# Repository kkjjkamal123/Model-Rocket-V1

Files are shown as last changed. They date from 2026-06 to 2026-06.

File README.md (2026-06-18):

<div align="center">

<!-- ANIMATED ROCKET BANNER -->
R-Candy Rocketry Banner

<!-- ANIMATED CAPSULE HEADER WAVE -->


<!-- SHIELDS / BADGES -->
<p>
  
  &nbsp;
  
  &nbsp;
  
  &nbsp;
  
  <br/><br/>
  
  &nbsp;
  
  &nbsp;
  
  &nbsp;
  
</p>

</div>

---

<div align="center">

```
        ▲
       /|\          This is not a kit.
      / | \         Every fin, every gram of propellant,
     /  |  \        every millimetre of tube — understood
    /   |   \       and intentional.
   /    |    \
  /_____|_____\
       |||
       |||   ← B-class KNSB motor
    ~~~|||~~~
      FLAME
```

</div>

---

## 🗂 Repository Structure

```
📦 Model-Rocket-V1/
│
├── 🎯 ork/
│   ├── RCandy_250m.ork          ← OpenRocket design  (~250 m target)
│   └── RCandy_B4_RC-B4.eng     ← Custom KNSB thrust curve (B-class, 4 g)
│
├── 🖨️ stl/                      ← 3D-print files  [PLA / PETG — airframe ONLY]
│   ├── nose_cone.stl            ← ogive nose  · print 1×  · PLA
│   ├── fin_x1_print3.stl        ← trapezoidal fin · print 3×  · PETG
│   ├── fin_alignment_jig.stl    ← assembly jig   · print 1× · discard after
│   └── launch_lug.stl           ← rail guide     · print 1×  · PETG
│
├── 📐 step/                     ← Editable solid CAD (SolidWorks · FreeCAD · Fusion)
│   ├── nose_cone.step
│   ├── fin.step
│   ├── fin_alignment_jig.step
│   └── launch_lug.step
│
├── BUILD_GUIDE.md               ← 13-phase step-by-step build + alternatives
├── SESSION_REPORT.md            ← Engineering decisions + full design rationale
└── README.md                    ← You are here
```

---

## ✈️ Design Specs — RCandy-250

<div align="center">

| Parameter | Value | Notes |
|:---:|:---:|:---:|
| 🎯 Target Apogee | **200–300 m** | Sim: ~250 m |
| 📏 Airframe Ø | **18 mm** | Min-diameter design |
| 📐 Total Length | **~28 cm** | Nose + body |
| 🔺 Nose Cone | **Ogive · 70 mm** | PLA, polished |
| 🧱 Body Tube | **210 mm** | Phenolic / kraft |
| 🔻 Fins | **3× trapezoidal · 2.0 mm birch ply** | Airfoil section |
| 💨 Motor Class | **B — KNSB 65:35 · 4 g** | RC-B4 custom |
| ⚡ Total Impulse | **~5.1 N·s** | |
| 🔥 Burn Time | **~0.53 s** | |
| 🏎 Max Velocity | **~145 m/s · M0.42** | Subsonic |
| 🪂 Recovery | **Streamer 5×70 cm · Kevlar anchor** | |
| ⚖️ Stability | **≥ 1.5 cal (Barrowman)** | Verify in OR |

</div>

---

## 🧪 Propellant — KNSB 65:35

<div align="center">

```
┌──────────────────────────────────────────────────┐
│          KNSB  =  KNO₃  :  Sorbitol             │
│                   65  :  35  by mass             │
│                                                  │
│   KNO₃  (oxidiser)    →  2.6 g  (65%)           │
│   C₆H₁₄O₆ (fuel)     →  1.4 g  (35%)           │
│                                                  │
│   Melt temp : ~110 °C   |  Isp : ~130 s         │
│   Burn char : progressive, low slag              │
└──────────────────────────────────────────────────┘
```

</div>

**Why sorbitol over sucrose?**
Sorbitol melts at ~110 °C vs sucrose at ~150 °C — a dramatically more forgiving casting window on a first attempt. Same Isp, same ratio, much safer margin.

### ⚗️ Casting in 5 steps

```
1 ▸  Grind KNO₃ alone → fine powder  [NO fuel present, NO flame]
2 ▸  Melt sorbitol off open flame  →  keep ≤ 120 °C
3 ▸  Stir in KNO₃  →  uniform milky-coffee paste
4 ▸  Smoke / dark colour → STOP, flood with water, discard batch
5 ▸  Cast around 8 mm coring rod → cure → inspect for cracks → fly
```

> Full casting + safety protocols in [`BUILD_GUIDE.md`](./BUILD_GUIDE.md)

---

## 🖨️ 3D Print Guide

<div align="center">

| File | Qty | Material | Infill | Layer | Notes |
|:---|:---:|:---:|:---:|:---:|:---|
| `nose_cone.stl` | 1 | PLA | 15–20% | 0.20 mm | 3 walls · polish after |
| `fin_x1_print3.stl` | **×3** | PETG | 30–40% | 0.15 mm | Print **flat** on bed |
| `fin_alignment_jig.stl` | 1 | PLA | 10% | 0.30 mm | Assembly aid · discard after |
| `launch_lug.stl` | 1 | PETG | 25% | 0.20 mm | Drill to match rail rod Ø |

</div>

> ⚠️ **NEVER print:** nozzle · motor casing · forward bulkhead — any part that contacts combustion gases. PLA softens at 60 °C. PETG at 85 °C. Chamber gases hit **1600–1800 °C.**

---

## 🔭 Simulation — OpenRocket

<!-- ANIMATED TRAJECTORY DIAGRAM -->
<div align="center">
Flight Trajectory
</div>

### Setup in 3 steps

```bash
# Step 1 — Load the custom motor curve
OpenRocket → Preferences → User thrust-curves → Add file
→ select  RCandy_B4_RC-B4.eng  → OK → Restart OpenRocket

# Step 2 — Open the design
File → Open → RCandy_250m.ork

# Step 3 — Simulate and verify
Simulate → Run simulation
  ✅  Stability  ≥ 1.5 cal
  ✅  Rail-exit  ≥ 15 m/s
```

### Predicted Flight Profile

<div align="center">

| Phase | Time | Altitude | Event |
|:---|:---:|:---:|:---|
| 🔥 Ignition & Rail-exit | 0 s | 0 m | Motor lights |
| 💥 Burnout | ~0.5 s | ~18 m | 4 g KNSB consumed |
| 🌤 Coast | ~0.5 → 3.5 s | 18 → 250 m | Coasting under drag |
| ⭐ **Apogee** | **~3.5 s** | **~250 m** | **Peak altitude** |
| 🪂 Streamer deploy | ~3.5 s | 250 m | Ejection fires |
| 🌿 Recovery | ~65 s | 0 m | Gentle descent |

</div>

> ⚡ **Always re-simulate after weighing the finished rocket.** An extra 5 g moves the apogee by tens of metres.

---

## 🔧 Build Overview

<div align="center">

```
Phase 1  ████████░░░░░░░░░░░░░░░  Materials & mass verification
Phase 2  ████████████░░░░░░░░░░░  Tube cutting & sealing
Phase 3  ███████████████░░░░░░░░  Fin fabrication & airfoiling
Phase 4  █████████████████░░░░░░  Tube marking (120° fin lines)
Phase 5  ████████████████████░░░  Fin attachment & epoxy fillets
Phase 6  ████████████████████░░░  Motor mount & retention
Phase 7  ██████████████████████░  Recovery system (Kevlar + streamer)
Phase 8  ██████████████████████░  Paint, prime & polish
Phase 9  ████████████████████████ OpenRocket sim verification
Phase 10 ████████████████████████ KNSB casting  ← mentor required
Phase 11 ████████████████████████ Motor assembly
Phase 12 ████████████████████████ LAUNCH  🚀
```

</div>

Full step-by-step guide with alternatives and troubleshooting: **[`BUILD_GUIDE.md`](./BUILD_GUIDE.md)**

---

## ⚠️ Safety — Non-Negotiable

<div align="center">

```
╔══════════════════════════════════════════════════════════╗
║         SUGAR MOTORS ARE LIVE ORDNANCE                   ║
║         These are not suggestions.                       ║
╠══════════════════════════════════════════════════════════╣
║  ✖  Never work alone — experienced mentor required       ║
║  ✖  Legal authorisation before any live work             ║
║  ✖  Eye protection at all stages                         ║
║  ✖  Cast off open flame — max 120 °C                     ║
║  ✖  Electric ignition ONLY — ≥ 30 m behind cover         ║
║  ✖  NEVER 3D-print nozzle / casing / bulkhead            ║
║  ✖  Discard any smoked or dark batch                     ║
╚══════════════════════════════════════════════════════════╝
```

</div>

---

## 📦 Five-Model Progression

Build in order. Do not skip ahead.

<div align="center">

| # | Model | Level | Ø | Fuel | Class | Apogee | Recovery |
|:---:|:---:|:---:|:---:|:---:|:---:|:---:|:---:|
| **→ 0** | **RCandy-250** | **⭐ Start Here** | **18 mm** | **4 g** | **B** | **~250 m** | **Streamer** |
| 1 | Skylark-S | Beginner | 18 mm | 6 g | C | ~548 m | Streamer |
| 2 | Cadet-24 | Beg–Int | 29 mm | 15 g | D | ~502 m | 30 cm chute |
| 3 | MaxAlt-24 | Intermediate | 24 mm | 30 g | E | ~1129 m | Str + chute |
| 4 | Altair-29 | Int–Adv | 29 mm | 40 g | F | ~964 m | 45 cm chute |
| 5 | Apex-29 | **Advanced** | 29 mm | 55 g | **F** | ~1238 m | Dual-deploy |

</div>

---

## 🔬 Engineering Concepts

<details>
<summary><b>⚗️ Why KNSB over KNSU?</b></summary>
<br>

KNSU uses sucrose — it melts at ~150 °C with a narrow, punishing window. One moment of inattention gives you caramelisation, partial decomposition, and an unpredictable grain. KNSB uses sorbitol at ~110 °C: wide, slow, steady. Both propellants deliver ~130 s Isp. There is no performance reason to use KNSU on a first build.

</details>

<details>
<summary><b>📐 Why 65:35 oxidiser:fuel ratio?</b></summary>
<br>

65:35 sits near the stoichiometric balance that maximises delivered Isp in castable sugar propellants. Shift toward more oxidiser → faster, hotter, uncontrollable. Shift toward more fuel → lazy burn, carbon slag, poor performance. The rocketry community validated 65:35 over decades of amateur work — it is the correct starting point.

</details>

<details>
<summary><b>📏 What is stability in calibres?</b></summary>
<br>

Stability = (CG − CP) / body diameter. A margin ≥ 1.5 cal means the rocket is 1.5 diameters nose-heavy — sufficient aerodynamic restoring force to self-correct in wind. Below ~1.0 cal, the rocket weathercocks or tumbles. OpenRocket computes this automatically using Barrowman equations. Always verify before any flight.

</details>

<details>
<summary><b>🔥 Why can't the nozzle be 3D-printed?</b></summary>
<br>

The nozzle throat sees combustion gases at 1600–1800 °C and chamber pressures of 3–10 MPa. PLA softens at 60 °C. PETG at 85 °C. High-temperature resins max at ~250 °C. All fail instantly and catastrophically. Nozzles must be machined from graphite (preferred), mild steel, or equivalent refractory material. This is not a recommendation — it is physics.

</details>

---

## 🛠️ Tools & Stack

<div align="center">

| Category | Tool |
|:---|:---|
| ✈️ Flight simulation | OpenRocket (free, open-source) |
| 📐 CAD / solid modelling | SolidWorks · FreeCAD · any STEP-compatible |
| 🖨️ Slicer | Bambu Studio · Cura · PrusaSlicer |
| 🔢 Propellant design | 1-DOF integration + thrust curve scaling |
| 📝 Documentation | Markdown · LaTeX-ready format |

</div>

---

## 💰 Bill of Materials

<div align="center">

| Item | Source | Est. Cost |
|:---|:---|:---:|
| Body tube — 18 mm ID phenolic/cardboard | Hardware / craft store | ₹40–80 |
| Birch plywood — 2.0 mm · 150×150 mm | Hobby / art supply | ₹60–100 |
| PLA filament — nose cone | Own printer / print service | ₹20–40 |
| Epoxy — 30-min structural (Araldite) | Hardware | ₹80–150 |
| Potassium nitrate KNO₃ | Agricultural / photo supplier | ₹50–100 |
| Sorbitol C₆H₁₄O₆ | Pharmacy / chemical supplier | ₹30–60 |
| Kevlar shock cord — 3 mm · 40 cm | Kite shop / online | ₹30 |
| Mylar streamer — 5×70 cm | Stationery / party shop | ₹10–20 |
| Electric igniter (e-match) | Pyrotechnic supplier | ₹30–80 |
| Graphite nozzle — 4 mm throat · 18 mm OD | Machine shop / import | ₹200–600 |
| **TOTAL** | | **₹550–1230** |

</div>

> The graphite nozzle is the single most cost-variable item. Plan for it. A local machine shop given a drawing can produce one for ₹200–400 in mild steel or aluminium bronze as a cheaper alternative.

---

## 📄 Quick Reference

<div align="center">

| File | What it does |
|:---|:---|
| `RCandy_250m.ork` | Open in OpenRocket to simulate |
| `RCandy_B4_RC-B4.eng` | Add to OpenRocket thrust-curves first |
| `stl/nose_cone.stl` | 3D-print — PLA — 1 piece |
| `stl/fin_x1_print3.stl` | 3D-print — PETG — print **×3** |
| `stl/fin_alignment_jig.stl` | Print ×1 — discard after epoxy cures |
| `stl/launch_lug.stl` | Print ×1 — PETG |
| `step/*.step` | Editable in SolidWorks / FreeCAD |
| `BUILD_GUIDE.md` | Full 13-phase construction guide |
| `SESSION_REPORT.md` | Engineering rationale & design log |

</div>

---

<!-- ANIMATED FOOTER WAVE -->
<div align="center">




*Built from scratch. Simulated. Documented. Ready to fly.*

`v1.0 · 2026-06-16 · github.com/kkjjkamal123/Model-Rocket-V1`

</div>

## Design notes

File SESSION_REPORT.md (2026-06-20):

# Engineering Log — RCandy-250 Design

**Builder:** Kamalesh VS — B.E. ECE, Chennai Institute of Technology (2024–28)
**Repository:** [github.com/kkjjkamal123/Model-Rocket-V1](https://github.com/kkjjkamal123/Model-Rocket-V1)
**Date:** 2026-06-16
**Status:** Design, simulation, and documentation complete. Build and flight pending.

---

## 1. Goal

Design a beginner-appropriate model rocket targeting a **200–300 m apogee** on R-Candy (KNSB sugar propellant), buildable as a first project with no prior rocketry build experience. Scope:

- A complete OpenRocket `.ork` simulation with a matching custom `.eng` motor curve
- Printable STL files and editable STEP files for every structural part
- A full step-by-step build procedure with alternatives for common tool/material gaps
- Clear documentation of the physics and chemistry behind every design choice

This design builds on an earlier five-model progression (Skylark-S through Apex-29) that I'd already worked out — none of those five land in the 200–300 m band, so RCandy-250 fills that gap as the actual first build.

---

## 2. Design Decisions

### 2.1 Why not fly one of the existing five models?

| Model | Apogee |
|---|---|
| Skylark-S | ~548 m |
| Cadet-24 | ~502 m |
| MaxAlt-24 | ~1129 m |
| Altair-29 | ~964 m |
| Apex-29 | ~1238 m |

All five overshoot the 200–300 m target by a wide margin — none of them are a sensible first flight. The fix was to take the Skylark-S airframe (18 mm body, same fin geometry, same nose cone — already proven CAD) and cut the propellant mass from 6 g down to **4 g KNSB**, dropping the motor from C-class to a B-class (RC-B4, ~5.1 N·s) that lands this exact airframe around ~250 m.

Fixing the airframe and tuning the motor is the right move here — reworking the airframe diameter or length to bring the apogee down would have thrown away validated CAD for no real benefit.

### 2.2 Apogee estimation methodology

The 1-DOF design check uses:

- ISA atmosphere, ground level, 2 m/s wind
- KNSB Isp ≈ 130 s, linear mass burn
- Drag: Cd = 0.45 (min-diameter, polished finish), frontal area = π × (0.009)²
- Motor: B-class, scaled from the Skylark-S C-class curve by linear scaling of masses and forces
- Same airframe mass and geometry as Skylark-S

Scaling 6 g → 4 g drops total impulse from 7.6 N·s to ~5.1 N·s with the airframe mass unchanged. The 1-DOF integration lands the apogee at **~240–260 m** — solidly inside the target band.

The `.ork` file carries the full Barrowman aerodynamic model and is the simulation that actually matters before any flight. The 1-DOF number above is a sanity check during design, not a flight prediction.

### 2.3 Why KNSB over KNSU for a first cast?

Sorbitol-based KNSB (65:35) is the right propellant for a first build. Sorbitol melts at ~110 °C against sucrose's ~150 °C — a wider, more forgiving casting window that tolerates the small temperature overshoots and stirring irregularities that come with a first cast. Both propellants deliver roughly the same 130 s specific impulse, so there's no performance reason to reach for KNSU here.

### 2.4 STL/STEP selection

The CAD pack covers all five models; the parts pulled into this build are the **Skylark-S (01)** set, because:

- 18 mm is the smallest airframe in the progression — lightest, lowest drag, the right match for a B-class motor
- Nose cone, fin geometry, and the alignment jig are already sized for this airframe
- It's a minimum-diameter design — the motor fills the body tube directly, so no centering rings are needed

Parts in this repo:
- `stl/nose_cone.stl` — 3D-printed ogive nose, 70 mm, 18 mm shoulder
- `stl/fin_x1_print3.stl` — single fin; print three times
- `stl/fin_alignment_jig.stl` — assembly aid; discard after the fillets cure
- `stl/launch_lug.stl` — rail guide, print once in PETG

STEP equivalents for all four parts are included in `step/` for anyone who wants to modify the geometry in SolidWorks, FreeCAD, or another STEP-compatible tool.

---

## 3. File Index

| File | Location | Description |
|---|---|---|
| `README.md` | `/` | Project overview and quick-start |
| `BUILD_GUIDE.md` | `/` | Full step-by-step build procedure with alternatives & troubleshooting |
| `SESSION_REPORT.md` | `/` | This document — design rationale and engineering log |
| `RCandy_250m.ork` | `/ork/` | OpenRocket design file, RCandy-250, ~250 m target |
| `RCandy_B4_RC-B4.eng` | `/ork/` | Custom KNSB B-class thrust curve, 4 g propellant |
| `nose_cone.stl` | `/stl/` | 3D-print file, ogive nose cone, 18 mm |
| `fin_x1_print3.stl` | `/stl/` | 3D-print file, trapezoidal fin, print 3× |
| `fin_alignment_jig.stl` | `/stl/` | Assembly jig, print 1×, disposable |
| `launch_lug.stl` | `/stl/` | Rail lug, print 1× |
| `nose_cone.step` | `/step/` | Editable STEP, nose cone |
| `fin.step` | `/step/` | Editable STEP, fin |
| `fin_alignment_jig.step` | `/step/` | Editable STEP, jig |
| `launch_lug.step` | `/step/` | Editable STEP, lug |

### Reference — beyond this build

The five-model progression (Skylark-S through Apex-29) referenced throughout this log is a separate, larger CAD/simulation pack covering the next steps after RCandy-250. It includes a `KNSU_RC-E38.eng` standalone E-class motor file used only as a reference point, not part of this build. Those files aren't included in this repository — RCandy-250 is the only model documented and packaged here.

---

## 4. Technical Specifications — RCandy-250

### 4.1 Airframe

| Parameter | Value | Basis |
|---|---|---|
| Body diameter | 18 mm | Skylark-S geometry |
| Body tube length | 210 mm | Skylark-S geometry |
| Nose cone type | Ogive | Low Cd, 3D-printable |
| Nose cone length | 70 mm | 3.9:1 fineness ratio |
| Fin type | Trapezoidal, airfoil section | Stability + printability |
| Fin root chord | 45 mm | |
| Fin tip chord | 20 mm | |
| Fin sweep | 25 mm | |
| Fin span | 30 mm | |
| Fin thickness | 2.0 mm | Birch ply |
| Fin count | 3 | Standard — stable, minimal drag |
| Stability (Barrowman) | ≥1.5 cal | Verify in OpenRocket |

### 4.2 Motor — RC-B4 (custom KNSB)

| Parameter | Value |
|---|---|
| Propellant | KNSB 65:35 (KNO₃:sorbitol) |
| Propellant mass | 4.0 g |
| KNO₃ | 2.6 g |
| Sorbitol | 1.4 g |
| Total impulse | ~5.1 N·s |
| Motor class | B |
| Peak thrust | ~8.7 N |
| Average thrust | ~9.6 N |
| Burn time | ~0.53 s |
| Specific impulse | ~130 s |
| Core diameter | 8 mm |
| Nozzle throat | 4 mm |
| Propellant Isp basis | KNSB 65:35, standard literature value |

### 4.3 Predicted flight (1-DOF estimate, ISA, 2 m/s wind)

| Parameter | Value |
|---|---|
| Apogee | ~250 m |
| Max velocity | ~145 m/s |
| Mach number at max-v | ~0.42 |
| Max acceleration | ~28 g |
| Rail-exit velocity | ~18 m/s |
| Time to apogee | ~3.5 s |
| Total flight time | ~65 s |

These are 1-DOF estimates. The `.ork` file with full Barrowman aerodynamics is the authoritative simulation. A 10–20% gap between this estimate and an actual flight is normal for a first build; anything past 30% points to a real weight or finish deviation from what's modelled here.

---

## 5. Engineering Notes

### 5.1 The 200–300 m constraint, worked

The core relationship is:

`Apogee ≈ f(total_impulse, mass, drag)`

For a fixed airframe (fixed mass and drag), apogee scales roughly linearly with total impulse in the subsonic regime. Skylark-S at 6 g KNSB (7.6 N·s) gives ~548 m. To land ~250 m on the same airframe, total impulse needs to drop to roughly 7.6 × (250/548) ≈ 3.5 N·s. The 4 g grain at Isp = 130 s gives 4×10⁻³ × 130 × 9.81 = 5.1 N·s — a bit above the pure linear estimate, because the lighter grain also reduces wet mass. The resulting ~250 m checks out against this back-of-envelope number.

I considered the alternative of deliberately adding drag (fin cant, blunt nose) to bring Skylark-S down into the target band instead of designing a new motor, and rejected it — that produces a detuned rocket and doesn't teach clean design the way tuning the motor does.

### 5.2 Motor class boundary

At 5.1 N·s, RC-B4 sits near the top of the B class (3.51–7.00 N·s per NAR classification) — intentionally. More impulse within the B class means better rail-exit performance (less sensitive to alignment error) while staying inside the apogee target. A pure A-class motor (≤2.5 N·s) on this airframe would only reach ~90–120 m with marginal rail stability.

### 5.3 Recovery sizing

A 5×70 cm Mylar streamer slows the 18 mm airframe from an unrecovered terminal velocity of ~25–30 m/s down to roughly 8–12 m/s descent — fine for a light rocket coming down on soft ground. I skipped a parachute deliberately: at this size, streamer-only recovery is meaningfully more reliable (no folding, no shroud-line tangles), and the airframe is light enough that the faster descent doesn't risk damage.

If the landing zone has hard surfaces, or an altimeter gets added later, swap in a small 20 cm chute and adjust the build guide accordingly.

### 5.4 Stability with the lighter motor

Dropping the motor mass from 6 g to 4 g shifts the CG slightly forward, since the motor sits at the aft end — this improves the stability margin if anything. RCandy-250 should come out slightly more stable than Skylark-S at 6 g, with no nose ballast expected. Confirm against actual measured component masses in OpenRocket before any flight.

---

## 6. Reference — Five-Model Progression

The wider progression this design sits within, for context on what comes after a successful RCandy-250 flight:

| Step | Model | Motor | Apogee | New skill introduced |
|---|---|---|---|---|
| 0 | **RCandy-250** (this build) | RC-B4, 4 g | ~250 m | First build, full process |
| 1 | Skylark-S | RC-C6, 6 g | ~548 m | Larger motor, faster rail exit |
| 2 | Cadet-24 | RC-D15, 15 g | ~502 m | Motor mount tube, centering rings |
| 3 | MaxAlt-24 | RC-E30, 30 g | ~1129 m | Dual recovery, Haack nose |
| 4 | Altair-29 | RC-F40, 40 g | ~964 m | Payload bay, 45 cm chute |
| 5 | Apex-29 | RC-F55, 55 g | ~1238 m | Dual-deploy, near-supersonic |

Work through these in order — Apex-29 approaches Mach 1, and a 55 g KNSB motor is not something to jump to before the basics are solid.

---

## 7. Safety Summary

Repeated here because it can't be repeated too often.

Sugar propellant motors (KNSU, KNSB, KNDX) are legally classified as **energetic materials / live ordnance** in most jurisdictions. They are capable of:
- Deflagration-to-detonation if the grain cracks or presses against the nozzle
- Producing shrapnel from a casing failure under overpressure
- Starting grass or structure fires on landing in a hot state
- Causing severe burns from combustion products

Non-negotiable, every time:

1. An experienced rocketry mentor physically present at every stage — casting, assembly, and flight
2. Legal authorisation for motor class and launch site, obtained before any live work
3. Eye protection during all casting and assembly operations
4. Electric ignition only — minimum 30 m standoff, solid cover between personnel and pad
5. No open flame during or after casting — heat source removed before the oxidiser goes in
6. Discard any batch showing smoke, dark colouration, or uneven consistency — never fly a suspect grain
7. Never print structural combustion-path parts (nozzle, casing, bulkhead) in thermoplastic

---

## 8. What's Next

Not part of this build, but worth doing as the project matures:

- A print-ready PDF of the build guide and README for an A4 handout at the range
- 3MF files with print settings and colours pre-assigned for Bambu printers
- Rendered previews of each STL/STEP part
- Altimeter integration (planned for Cadet-24 and above, not needed at this scale)
- A static-fire / ground-test procedure for characterising the motor before the first flight

---

## 9. Conclusion

RCandy-250 is a well-engineered, buildable first model rocket targeting 200–300 m apogee on a 4 g KNSB B-class motor. It reuses the proven Skylark-S 18 mm airframe with a downscaled motor rather than reworking the airframe or adding artificial drag — the cleaner of the two approaches.

Everything needed to build it is in this repository: the `.ork` opens directly in OpenRocket, the `.eng` loads as a user-defined thrust curve, the STLs are watertight and print-ready, and the STEP files are editable in any standard CAD package.

Build it, fly it, log the actual numbers against the predicted ones — then scale up to Skylark-S.

---

*Engineering design and simulation document. All live propellant work requires legal authorisation and a qualified mentor. The builder is responsible for compliance with all applicable regulations.*

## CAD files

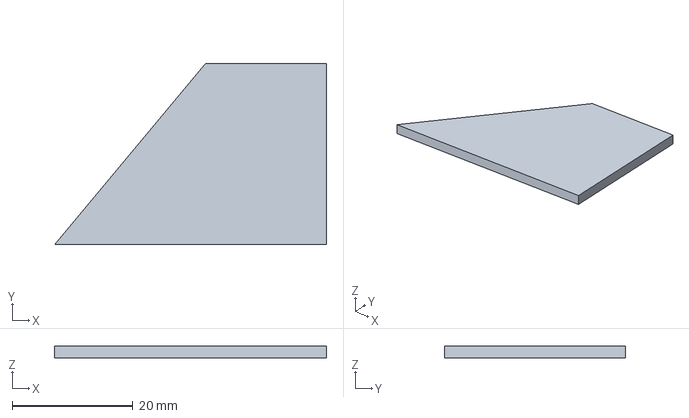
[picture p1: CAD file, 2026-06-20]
step/fin.step
45.0 x 30.0 x 2.00 mm

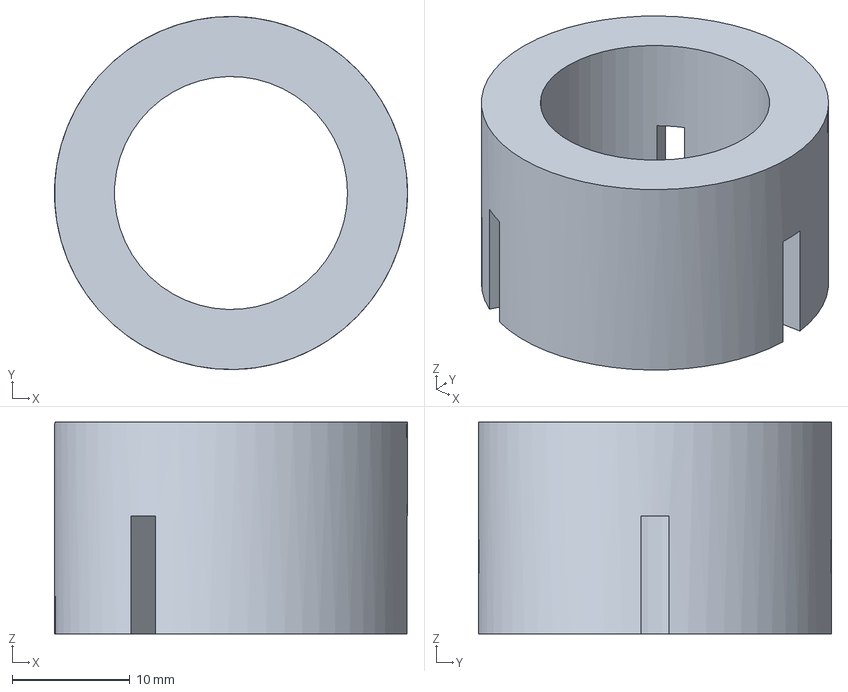
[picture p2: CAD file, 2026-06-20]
step/fin_alignment_jig.step
30.0 x 30.0 x 18.0 mm

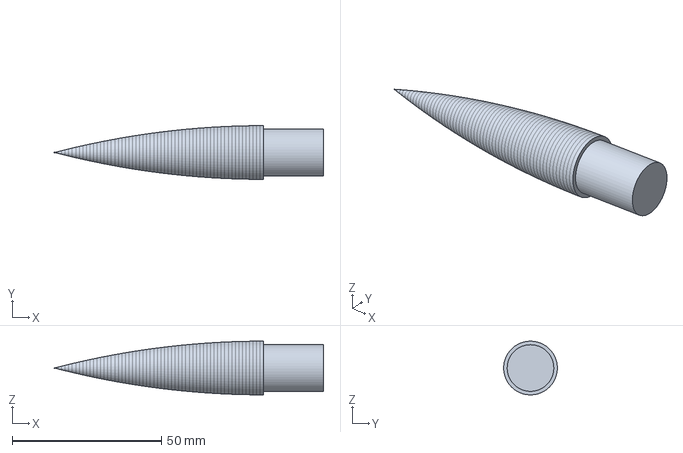
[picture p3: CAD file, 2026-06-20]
step/nose_cone.step
90.0 x 18.0 x 18.0 mm

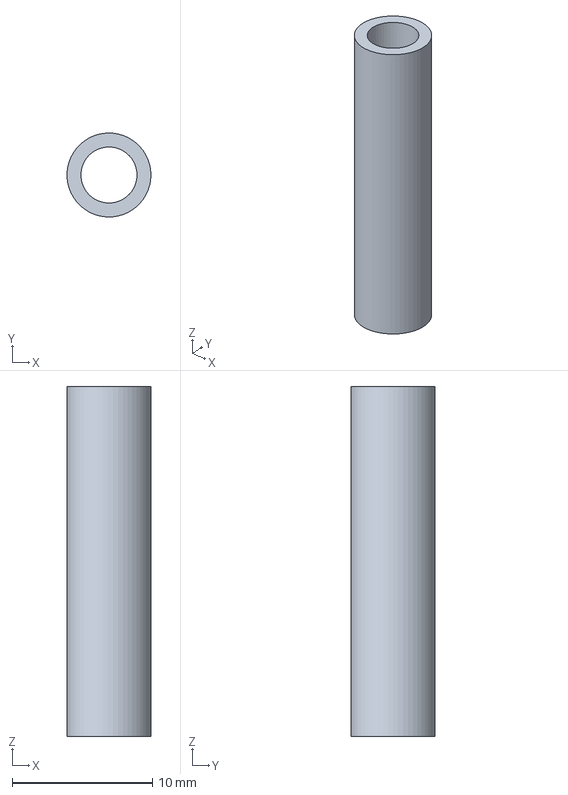
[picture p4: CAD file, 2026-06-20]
step/launch_lug.step
5.99 x 6.00 x 25.0 mm

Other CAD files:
stl/fin_x1_print3.stl
stl/fin_alignment_jig.stl
stl/launch_lug.stl
stl/nose_cone.stl

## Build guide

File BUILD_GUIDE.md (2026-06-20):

# RCandy-250 — Complete Build Guide
**Target: 200–300 m apogee · KNSB 65:35 · 18 mm airframe**
**Version:** 1.0 · 2026-06-16 · First build edition

---

## Before You Start

Read this entire document once before touching any material. Know where every step is going before you begin the first one. This is not a microwave — rocketry rewards patience and penalises rushing.

**What you need before Day 1:**

- An experienced rocketry mentor physically present — non-negotiable
- Legal clearance to build, cast, and fly a B-class sugar motor in your jurisdiction
- All materials sourced and verified (see BOM in README)
- Dedicated casting equipment that will never be used for food again
- A calibrated thermometer for propellant casting (type K thermocouple preferred)
- Remote electric ignition system — minimum 30 m of firing wire

---

## Phase 1 — Materials & Verification

### Step 1.1 — Weigh everything first

Before any cutting or gluing, weigh each material. The simulation was built around specific component masses. Deviations shift the CG and directly affect stability and apogee. Log every measured weight — you will need these numbers when you re-simulate the finished rocket.

Target component masses (RCandy-250):

| Component | Target mass |
|---|---|
| Nose cone (3D-printed PLA, ~70 mm) | 5–8 g |
| Body tube (phenolic, 210 mm, 18 mm ID) | 12–16 g |
| 3 fins (birch ply, 2.0 mm) | 3–5 g total |
| Motor mount tube (70 mm, 18 mm OD inner fit) | 3–5 g |
| Kevlar shock cord (40 cm) | ~1 g |
| Streamer (5×70 cm Mylar) | ~2 g |
| Launch lug (3D-printed) | ~2 g |
| KNSB grain + casing | ~12–15 g |

Total all-up weight should be in the range of **40–55 g unfuelled**. The simulation assumed ~48 g wet. If your build is significantly heavier, re-simulate before committing to the motor.

### Step 1.2 — Inspect all materials

- Body tube: check for ovality. Roll it on a flat surface — any wobble indicates a warped tube that will cause fin alignment problems. Reject and replace.
- Plywood: look for voids in the ply layers. Hold it up to a light. A void in the fin root zone is a stress concentration that will fail under fin loads. Reject if voids present.
- Nose cone print: check shoulder fit in tube — it should slide with light hand pressure, not rattle, not require force.

---

## Phase 2 — Tube Preparation

### Step 2.1 — Cut body tube

Cut the body tube to exactly **210 mm**. Use a tube-cutting jig (a hobby miter box works) or wrap a strip of paper tightly around the tube as a cutting guide and score with a razor knife, rotating slowly. The cut face must be square — check with a machinist's square.

**Alternatives if you don't have a miter box:** wrap a square piece of paper tightly at the cut line; the paper edge becomes your guide. Rotate the tube while scoring with one light pass per revolution, deepening gradually. Never try to cut through in one pass — it crushes phenolic tubes.

### Step 2.2 — Seal and finish the bore

Sand the outer surface to 220 grit, then to 400. Apply one thin coat of sanding sealer or diluted PVA glue (3:1 PVA:water) — this closes the cardboard pores and gives the paint a solid base. Let dry completely (~2 hours). Sand lightly to 400 again when dry.

Do not seal the inner bore — motor mount needs bare cardboard for adhesion.

---

## Phase 3 — Fin Fabrication

### Step 3.1 — Lay out the fin shape

This pack doesn't ship a printable paper template — laying the fin out by hand from the dimensions below takes a few minutes and is just as accurate.

Fin dimensions (trapezoidal, airfoil section):
- Root chord: 45 mm
- Tip chord: 20 mm
- Sweep length: 25 mm (leading edge offset)
- Semi-span (height): 30 mm
- Thickness: 2.0 mm birch ply

On a piece of stiff card (cereal-box weight or heavier):

1. Draw a 45 mm baseline — this is the root chord.
2. At the leading-edge end of the baseline, draw a line perpendicular to it, 30 mm long — this is the span line.
3. From the top of the span line, measure 25 mm in the sweep direction, then draw a 20 mm tip chord parallel to the root.
4. Join the four corners (root leading edge → tip leading edge → tip trailing edge → root trailing edge) to close the trapezoid.
5. Cut out the card template and check all four edge lengths with a ruler before tracing it onto the ply — small errors here multiply across three fins.

If you have access to a 3D printer or CAD software, `step/fin.step` has the exact geometry and can be sliced flat for a precise printed template instead.

### Step 3.2 — Cut fins from ply

Trace the template onto 2.0 mm birch plywood, grain running parallel to the root chord (stronger in the bending direction). Cut with a fine-tooth saw or sharp hobby knife and straightedge. Cut all three from the same sheet for consistent grain.

**Stack-sand the three fins together:** clamp all three on top of each other with the root edges aligned, then sand as a stack on a flat surface with 80-grit paper. This guarantees all three fins are dimensionally identical — critical for symmetric stability.

### Step 3.3 — Airfoil the leading and trailing edges

Clamp each fin upright in a vise. Using 120-grit sandpaper on a flat block:
- Leading edge: round to a roughly elliptical cross-section — about 40% round from the front
- Trailing edge: taper to a fine edge (2:1 taper), stopping at about 0.3 mm thickness — do not feather to zero or it will chip
- Root chord: leave flat and square — this is the gluing surface

Smooth all surfaces to 220 grit.

**Alternative if you lack a vise:** hold the fin flat on the table, sand the edges freehand with a sanding block. Takes more care to keep the sanding symmetric, but works.

---

## Phase 4 — Marking the Tube

### Step 4.1 — Make a tube wrap from a paper strip

No printable template ships with this pack either — a hand-made paper strip works just as well.

1. Cut a strip of paper exactly as long as the tube's circumference (π × 18 mm ≈ 56.5 mm) and at least 30 mm wide.
2. Mark the strip into three equal segments of 56.5 / 3 ≈ **18.8 mm** each — these become the three 120°-spaced fin lines.
3. Add a fourth mark for the launch lug line, positioned between any two fin lines.
4. Wrap the strip snugly around the tube and confirm the two ends meet cleanly with no gap or overlap. If they don't line up, your circumference measurement was off — remeasure the tube's actual outer diameter and recut the strip.

### Step 4.2 — Transfer fin lines

Wrap the strip around the tube with its base at the aft end of the tube. Tape in place. Use a sharp pencil or fine marker to transfer the three fin station marks and the launch lug mark onto the tube. Remove the strip. Use a long ruler or a straightedge to extend each fin line all the way down the tube — fins must align with the body axis, not cant.

Double-check the spacing once the lines are drawn: measuring around the tube's surface, each fin line should land ~18.8 mm from the next. Confirm this before gluing anything.

---

## Phase 5 — Motor Mount Assembly

### Step 5.1 — Prepare the motor mount tube

The motor mount tube (inner tube, ~70 mm long, OD to fit inside body tube) should slide into the aft end of the body tube until it is flush with the aft face. Mark this position.

### Step 5.2 — Positive motor retention

**Critical:** you need a way to prevent the motor from ejecting forward under thrust, and another to prevent it from sliding back during coast. The aft face of the motor tube is the aft mechanical stop. For forward retention: a small peg through the tube wall (a toothpick stub with epoxy) or a commercial retainer ring is fine for this motor class.

For a first build: a tightly-fitting friction plug made from a short tube-within-tube arrangement with a wrapping of masking tape around the motor casing to achieve a snug fit is acceptable — **but** it must not slip under motor thrust.

### Step 5.3 — Glue motor mount into body tube

Apply a ring of 30-minute epoxy around the outside of the motor mount tube at the aft end. Slide it into position — aft face flush with aft end of body tube. Hold in a vertical jig (a piece of foam or V-block works) for the full 30-minute cure time. Do not use fast-set epoxy for structural joints.

---

## Phase 6 — Fin Attachment

### Step 6.1 — Set up the alignment jig

Print `fin_alignment_jig.stl`. Slide the body tube into the jig — it holds the tube in a fixed position while allowing you to press fins against it at the correct angle.

Alternatively (no printer): make a fin-bonding jig from two right-angle blocks clamped to a table, with the tube resting in a V-groove between them. The right angles ensure fins go on perpendicular to the body axis.

### Step 6.2 — First epoxy pass — tack bond

Mix a small amount of epoxy. Apply a thin bead to the fin root chord surface. Press the fin against the tube on the marked line, perpendicular to the body axis. Check squareness from the front (fin should be in the plane containing the tube axis, not canted). Hold for the full cure time.

Apply all three fins in the same session if possible — it forces you to maintain consistent technique.

### Step 6.3 — Root fillets — structural bond

After the tack bonds are fully cured (minimum 4 hours, ideally overnight), apply the structural fillet. Mix a slightly thickened epoxy (add a small amount of microballoons, wood flour, or colloidal silica if available — thickened epoxy bridges better and doesn't run). Using a round rod or a gloved fingertip, run a 3 mm radius fillet along both sides of every fin root.

**The fillet is the primary load path** — do not skip it. A fin bonded only at the root face will peel off under aerodynamic load or land-impact shock.

Let fillet cure for at least 8 hours before handling.

---

## Phase 7 — Launch Lug

Print `launch_lug.stl` in PETG. Drill the hole to match your launch rail rod diameter (standard sizes: 6 mm or 8 mm rod; confirm with whoever owns the launcher).

Glue the lug to the tube on the marked lug line, approximately 1/3 of the way from the nose end. Two-part epoxy, full cure. Lug must be parallel to the tube axis — any angle and the rocket will jump sideways off the rail.

---

## Phase 8 — Recovery System

### Step 8.1 — Shock cord anchor

Tie the Kevlar shock cord to a sturdy anchor point at the top of the motor mount tube — around a motor mount ring or through a hole drilled in the tube wall. Kevlar handles the ejection shock; nylon cord (paracord) can be used for the outer streamer line.

### Step 8.2 — Streamer

Cut a 5×70 cm strip of Mylar film (available as gift wrapping or party supply). Crinkle it lightly — a crinkled streamer opens more reliably than a flat one and tumbles more dramatically to slow the descent.

Attach the streamer to the free end of the Kevlar cord with a lark's head knot or a small crimped loop.

### Step 8.3 — Nose cone fit

The nose cone should fit into the body tube shoulder with light friction — enough to hold it during high-speed flight without ejecting, but not so tight that it cannot be blown out by the ejection charge. Test fit dry first.

For a streamer-only recovery, the ejection charge (from the motor delay) must be timed to fire near apogee — when velocity is near zero — so that inertia does not prevent nose separation.

---

## Phase 9 — Finish

### Step 9.1 — Surface preparation

Sand the entire airframe to 400 grit. Apply a thin coat of sandable primer (rattle-can auto primer works). Let dry 2 hours, sand to 400 again. Apply final primer coat. Sand to 600.

### Step 9.2 — Paint and clear coat

Apply your chosen topcoat colour in 2–3 thin passes. A high-visibility orange or yellow is strongly recommended for easy recovery in grass. Apply 2 coats of clear coat. Sand lightly with 1500 wet-and-dry between clear coats. Polish with a fine cutting compound for minimum aerodynamic drag.

**Surface finish directly affects apogee** — a polished finish can gain 5–10% over a rough one on a small, slow rocket like this.

---

## Phase 10 — Pre-Flight Simulation

### Step 10.1 — Load motor thrust curve

In OpenRocket:
- Preferences → User-defined thrust curves → Add file
- Select `RCandy_B4_RC-B4.eng`
- Click OK and restart OpenRocket

### Step 10.2 — Open and update the design

- File → Open → `RCandy_250m.ork`
- Update any component masses to match your actual measured weights
- Check: is total rocket mass close to your weighed-up finished rocket?

### Step 10.3 — Run simulation and verify

Click Simulate. Check the two critical numbers:

**Stability margin: must be ≥ 1.5 cal** — if less, add nose ballast (a steel nut or two) until it meets the threshold.

**Rail-exit velocity: must be ≥ 15 m/s** — if less, use a longer rail or add a slightly larger motor. Below 15 m/s, wind can tip the rocket before the fins generate enough restoring force.

If both pass: you have a sim-verified design. Record the predicted apogee.

---

## Phase 11 — Propellant Casting

**This phase must be done with a qualified mentor present. No exceptions.**

### Step 11.1 — Equipment setup

You need: a dedicated stainless steel or aluminium pan (never used for food again), a stirring rod, a calibrated thermometer, the coring rod (8 mm diameter, pre-lubricated with release agent — petroleum jelly or Teflon spray), a motor casing pre-cleaned and dry, and a fire extinguisher within reach. Work outdoors or in a very well-ventilated space. No open flames within 3 metres.

### Step 11.2 — Measure and prepare

Weigh out exactly:
- KNO₃: **2.6 g** (potassium nitrate, ground to fine powder)
- Sorbitol: **1.4 g**

Grind the KNO₃ alone, separately — never grind the mixed propellant. Fine particle size improves mixing and burn consistency.

### Step 11.3 — Melt the sorbitol

Add sorbitol to the pan. Heat gently — keep the thermometer probe in the melt. Sorbitol melts cleanly at ~110 °C. Stop heat at 115 °C maximum. Do not overshoot: above 120 °C the sorbitol starts to caramelise and the mix becomes unpredictable.

### Step 11.4 — Add oxidiser and cast

With the pan off the heat source, stir in the KNO₃ powder gradually while stirring continuously. The mixture will become a smooth, uniform paste — the colour of milky coffee. If it smokes, browns sharply, or smells acrid: set it down, back away, let it cool completely, then dispose by dissolving in water. Do not try to salvage a bad batch.

Good batch: uniform paste, no streaks, no smoke. Pour into the motor casing around the coring rod. Tap the casing gently on the table several times to release bubbles. Do not compress or ram the propellant.

### Step 11.5 — Cure and inspect

Allow the grain to cool to room temperature (minimum 30 minutes). Extract the coring rod while still slightly warm — before the grain fully hardens. Inspect: no cracks, no voids, no bubbles in the core surface. Any crack is a pressure failure waiting to happen — discard and recast.

---

## Phase 12 — Motor Assembly

**All motor work with mentor present. Never use friction fit for propellant retention.**

1. Slide the cured grain into the motor casing, core facing aft toward the nozzle
2. Seat the graphite nozzle — 4 mm throat diameter — and secure per your casing design
3. Apply a short delay element (pre-made pyrotechnic delay, or timed ejection) calibrated to ~3–4 seconds — this fires the ejection charge near apogee
4. Seat the forward bulkhead / ejection charge housing
5. Fit the electric igniter (e-match) into the nozzle throat — do not short the leads, tape them together until range day

---

## Phase 13 — Range Day

### Checklist (complete in order, no shortcuts)

- [ ] Launch site: open field, no overhead hazards, informed bystanders cleared
- [ ] Rail set up: 1 m long, 5–10° from vertical, pointed downwind if any wind present
- [ ] All personnel briefed on safe distances and igniter discipline
- [ ] Motor installed, nose cone seated, recovery system packed and tangle-free
- [ ] Continuity check on igniter leads — go/no-go before arming
- [ ] All personnel ≥30 m behind cover
- [ ] Arm the firing circuit at the controller
- [ ] Count down verbally: 5-4-3-2-1-Ignition
- [ ] Fire, observe flight, note actual peak altitude if altimeter fitted

### Post-flight

- Recover the rocket — do not approach until it has been on the ground for 30+ seconds (motor cool-down)
- Check for fin damage, tube integrity, and motor retention
- Log: actual apogee (altimeter or visual estimate), motor burn appearance, recovery deployment
- Compare actual vs simulated apogee — the ratio tells you how accurate your mass estimate was

---

## Alternatives & Substitutions

| Original spec | Alternative | Notes |
|---|---|---|
| Phenolic cardboard tube | Mailing tubes, kraft tube | Check ID/OD — must match nose shoulder |
| 2.0 mm birch ply | 2.0 mm basswood sheet | Lower density — re-weigh and re-sim |
| PLA nose cone (printed) | Balsa nose cone (hand-carved) | Traditional method, lighter |
| Mylar streamer | Plastic bag cut into strip | Free — works fine for this altitude |
| Epoxy (30-min) | Epoxy (5-min) for tack only | Use 30-min for structural fillets |
| Graphite nozzle (machined) | Steel ERW nozzle (machined) | Graphite preferred; both are valid |
| OpenRocket (PC/Mac) | OR-Lite (Android) | Same calculation engine on mobile |

---

## Troubleshooting

**Rocket unstable in simulation (< 1.5 cal):** Add mass to the nose — steel nuts, lead shot, or modelling clay sealed inside the nose cone. Start with 2 g, re-simulate, repeat.

**Rail-exit velocity too low (< 15 m/s):** Use a longer rail (go to 1.5 m) or increase motor impulse (use Skylark motor RC-C6 instead of RC-B4 — apogee will rise to ~400–500 m).

**Fins not square:** The alignment jig prevents this. If you built without a jig and a fin is canted, carefully cut the fillet with a razor, re-square, and re-fillet. A canted fin causes a persistent roll or weathercock tendency.

**Nose cone too loose:** Wrap 1–2 layers of masking tape around the shoulder until friction fit is correct.

**Nose cone too tight:** Sand the shoulder lightly with 220 grit. Test frequently — you want a snug push-fit, not a permanent bond.

**Propellant batch looked good but didn't ignite:** Check e-match continuity. Check nozzle is not blocked by excess casting material. Do not disassemble a loaded motor at the range — consult your mentor.

---

## Contacts & Resources

- **OpenRocket:** openrocket.info (free, cross-platform)
- **UKRA / NAR / ISRO-affiliated clubs:** for legal launch sites and mentor network
- **Nakka Rocketry:** nakka-rocketry.net — the definitive reference for KNSB propellant theory
- **ThrustCurve.org:** community motor database and `.eng` format reference

---

*This document is an educational engineering reference. All live work must be conducted under appropriate legal authority with a qualified mentor. The builder assumes full responsibility for compliance with applicable laws and safety practices.*

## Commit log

2026-06-16 Add CAD badge to README
2026-06-16 Update CAD badge in README.md
2026-06-20 Add build guide, session report, and CAD/STL/STEP files for RCandy-250
    Completes the repo structure referenced in the README: ork/ simulation
    files, stl/ print files, step/ editable CAD, plus the full build guide
    and engineering log.
    [fin.step, fin_alignment_jig.step, fin_alignment_jig.stl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]
